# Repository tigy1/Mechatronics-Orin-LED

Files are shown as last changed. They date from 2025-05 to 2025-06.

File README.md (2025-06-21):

# Orin Robosub LED Mode Indicator

This repository contains the firmware and host-side interface for controlling a WS2812 LED strip via an STM32 microcontroller over UART. The LEDs are used to indicate the **current operational mode** of the Orin Robosub, a student-built autonomous underwater vehicle.

Modes are communicated via UART from a Python script running on the host system and translated into LED color patterns by the STM32 firmware.

---

## Purpose

LEDs provide **immediate visual feedback** on Orin’s state. This is crucial during pool testing, debugging, or when operating the sub remotely. Modes are mapped to colors, enabling surface crew to distinguish between autonomous navigation, manual override, kill switch activation, and other states.

---

## Architecture Overview

### Hardware Components

- **Microcontroller**: STM32 (e.g., STM32F103 or similar)
- **LED Strip**: WS2812B addressable RGB strip
- **Communication**: UART @ 115200 baud between host and STM32
- **Power Supply**: Regulated 5V for LED strip

### Firmware Features (`main.c`)

- Configures **TIM2 PWM with DMA** for LED signal generation
- Parses RGB input strings over UART
- Allows **real-time LED updates** from Python terminal input
- Implements **chasing animation** based on current mode color
- Brightness control via `tan()` mapping for perceived brightness tuning

### Python Host Interface (`led_script.py`)

- Validates and sends RGB values to STM32 over UART
- Command-line interface prompts for interactive control
- Cross-platform support with adjustable serial port

---

## Getting Started

### Clone the Repository

```bash
git clone https://github.com/tigy1/Mechatronics-Orin-LED.git
cd Mechatronics-Orin-LED
```

### Build and Flash Firmware

- Use **STM32CubeIDE** or compatible toolchain
- Connect your board via ST-Link or UART bootloader
- Ensure `NUMBER_OF_LEDS` is configured correctly in `main.c`
- Flash `main.c` and its dependencies (`led.c`, `led.h`) to your board

### Install Python Dependencies

No external libraries beyond `pyserial` are required:

```bash
pip install pyserial
```

---

##  Using the Control Script

Run the Python control interface:

```bash
python3 led_script.py
```

You will be prompted to enter RGB values in the format:

```
### ### ### where each chain of hashtags represents a number 001 - 255 (0s are important) as a decimal representation of RGB values.

To disable LED output via DMA, send: `001 000 000`
```

The script will validate input and send it via UART to the STM32 board.

*Adjust `port` and `baudrate` if needed inside `led_script.py`.*

---

## Code Highlights

### UART Packet Format

The STM32 expects newline-terminated ASCII RGB strings over UART:

```
"255 000 000\n"
```

Parsed using `sscanf` in `HAL_UART_RxCpltCallback()`.

### LED Color and Brightness Encoding

Color bits are stored as bitwise-shifted PWM values in structs:

```c
typedef struct {
  uint16_t r[8], g[8], b[8];
} led;
```

Brightness mapping uses `tan(angle)` to provide nonlinear control.

### DMA Timing

Each LED gets 24 bits; additional 2 LEDs are padded to ensure reset timing:

```c
NUMBER_OF_LEDS * 24 + 2 * 24
```

---

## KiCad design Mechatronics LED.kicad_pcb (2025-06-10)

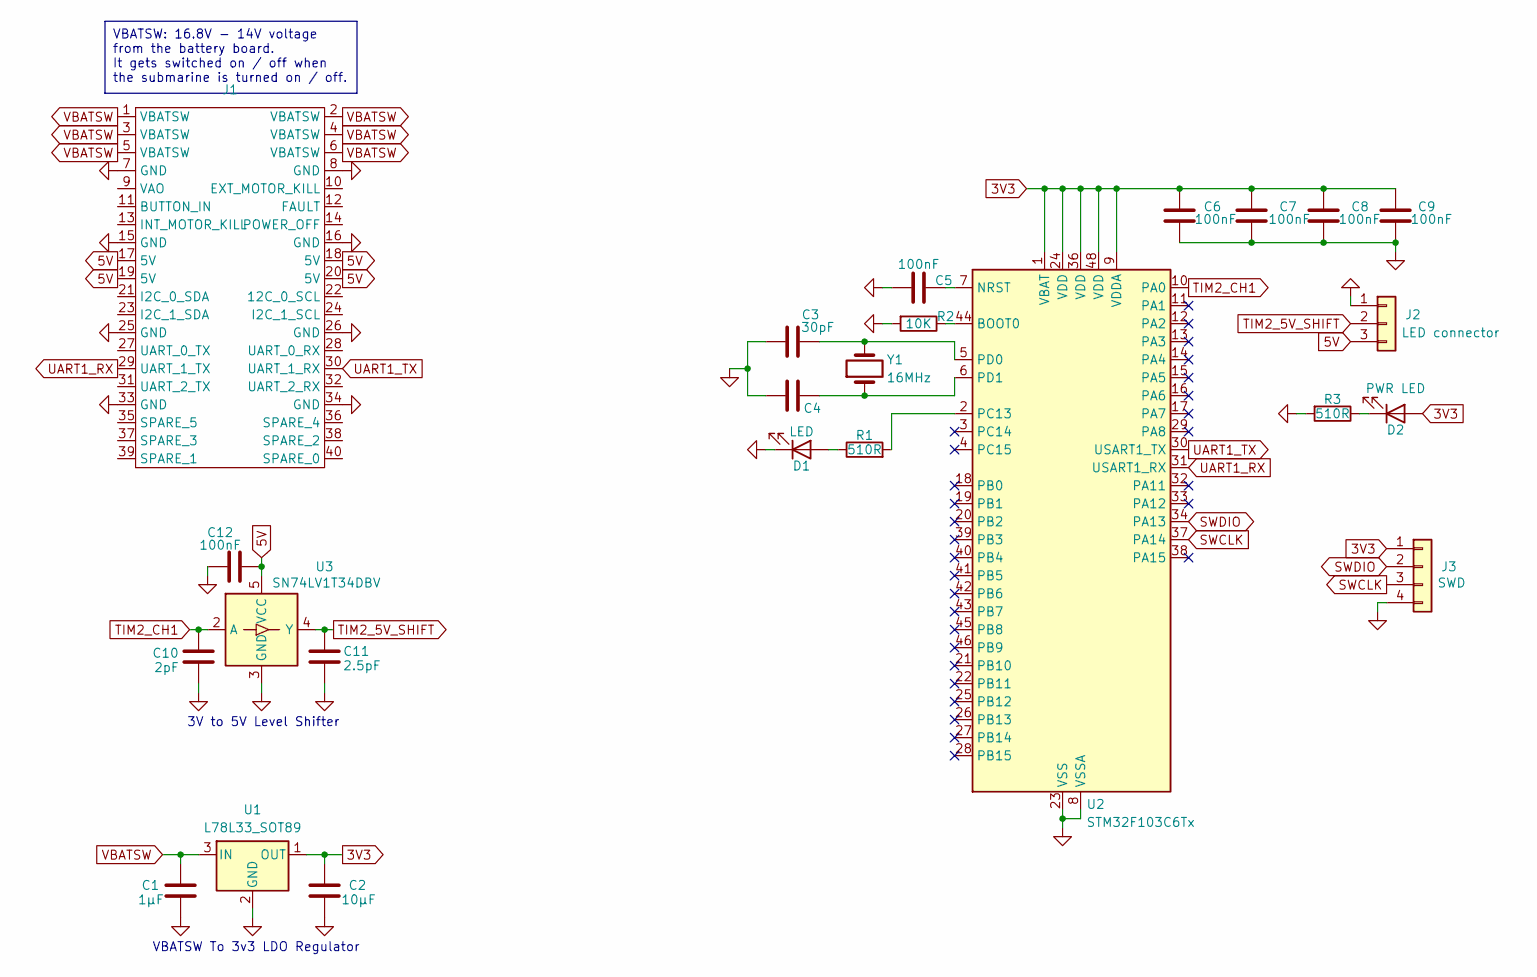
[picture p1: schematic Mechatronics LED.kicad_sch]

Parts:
C1: 1μF; C_0805_2012Metric
C2: 10μF; C_0805_2012Metric
C3, C4: 30pF; C_0805_2012Metric
C5, C6, C7, C8, C9, C12: 100nF; C_0603_1608Metric
C10: 2pF; C_0805_2012Metric
C11: 2.5pF; C_0805_2012Metric
D1: LED; LED_0805_2012Metric
D2: PWR LED; LED_0805_2012Metric
J1: PinHeader_2x20_P2.54mm_Vertical
J2: LED connector; PinHeader_1x03_P2.54mm_Vertical
J3: SWD; PinSocket_1x04_P2.54mm_Vertical
R1, R3: 510R; R_0805_2012Metric
R2: 10K; R_0805_2012Metric
U1: L78L33_SOT89; SOT-89-3
U2: STM32F103C6Tx; LQFP-48_7x7mm_P0.5mm
U3: SN74LV1T34DBV; SOT-23-5
Y1: 16MHz; Crystal_HC49-4H_Vertical

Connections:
3V3: C2.1, C6.1, C7.1, C8.1, C9.1, D2.2 (A), J3.1, U1.1 (OUT), U2.1 (VBAT), U2.9 (VDDA), U2.24 (VDD), U2.36 (VDD), U2.48 (VDD)
5V: C12.2, J1.17 (5V), J1.18 (5V), J1.19 (5V), J1.20 (5V), J2.3, U3.5 (VCC)
GND: C1.2, C2.2, C3.1, C4.1, C5.1, C6.2, C7.2, C8.2, C9.2, C10.2, C11.2, C12.1, D1.1 (K), J1.7 (GND), J1.8 (GND), J1.15 (GND), J1.16 (GND), J1.25 (GND), J1.26 (GND), J1.33 (GND), J1.34 (GND), J2.1, J3.4, R2.2, R3.2, U1.2 (GND), U2.8 (VSSA), U2.23 (VSS), U2.35 (VSS), U2.47 (VSS), U3.3 (GND)
unnamed: D1.2 (A), R1.1
unnamed: D2.1 (K), R3.1
unnamed: R2.1, U2.44 (BOOT0)
unnamed: C5.2, U2.7 (NRST)
unnamed: R1.2, U2.2 (PC13)
unnamed: C3.2, U2.5 (PD0), Y1.2
unnamed: C4.2, U2.6 (PD1), Y1.1
SWCLK: J3.3, U2.37 (PA14)
SWDIO: J3.2, U2.34 (PA13)
TIM2_5V_SHIFT: C11.1, J2.2, U3.4 (Y)
TIM2_CH1: C10.1, U2.10 (PA0), U3.2 (A)
UART1_RX: J1.29 (UART_1_TX), U2.31 (USART1_RX)
UART1_TX: J1.30 (UART_1_RX), U2.30 (USART1_TX)
VBATSW: C1.1, J1.1 (VBATSW), J1.2 (VBATSW), J1.3 (VBATSW), J1.4 (VBATSW), J1.5 (VBATSW), J1.6 (VBATSW), U1.3 (IN)

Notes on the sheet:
VBATSW: 16.8V - 14V voltage from the battery board. It gets switched on / off when the submarine is turned on / off.
3V to 5V Level Shifter
VBATSW To 3v3 LDO Regulator

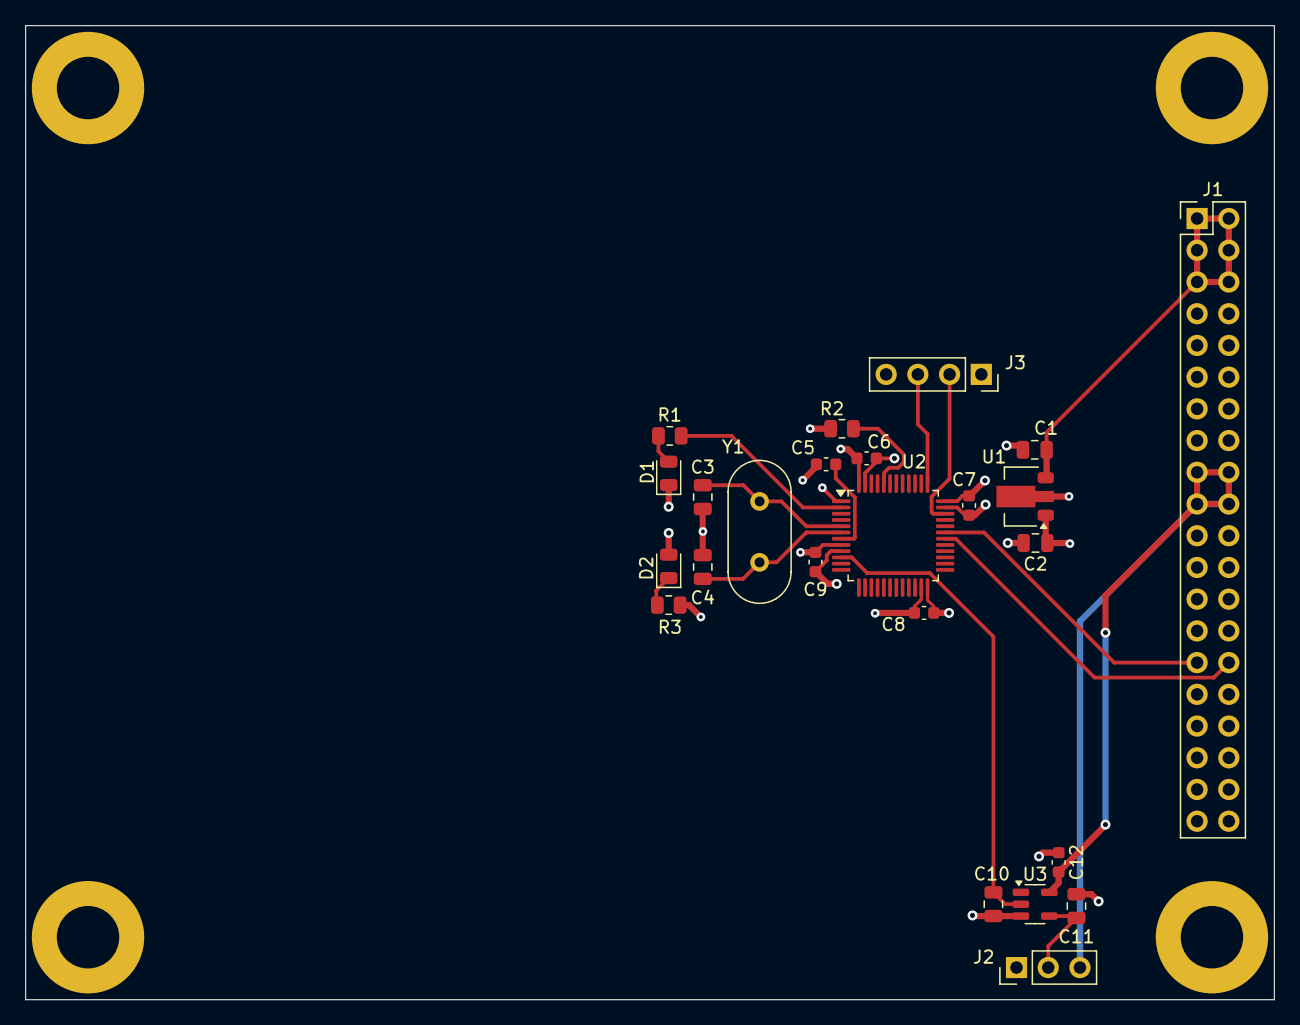
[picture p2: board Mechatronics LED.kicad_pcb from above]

Board: 4 copper layers, 100.0 x 78.0 mm, 24 parts (0 on the bottom side), 17 nets.

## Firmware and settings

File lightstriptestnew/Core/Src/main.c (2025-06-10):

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
/* Includes ------------------------------------------------------------------*/
#include "main.h"

/* USER CODE BEGIN Includes */
#include <stdio.h>
#include "string.h"
#include "led.h"
/* USER CODE END Includes */

/* USER CODE BEGIN PD */
#define NUMBER_OF_LEDS 7 //configure to # of leds
#define BRIGHTNESS 20 //configure value from 0-44, 0 = dimmest, 44 = brightest
/* USER CODE END PD */

TIM_HandleTypeDef htim2;
DMA_HandleTypeDef hdma_tim2_ch1;

UART_HandleTypeDef huart1;

/* USER CODE BEGIN PV */
led leds[NUMBER_OF_LEDS + 2]; //dma data send buffer
uint8_t RxColor[13]; //uart receive buffer
rgb_color realRGB; //LED lights as RGB values
/* USER CODE END PV */

void SystemClock_Config(void);
static void MX_GPIO_Init(void);
static void MX_DMA_Init(void);
static void MX_TIM2_Init(void);
static void MX_USART1_UART_Init(void);
/* USER CODE BEGIN 0 */

void HAL_UART_RxCpltCallback(UART_HandleTypeDef* huart){
	sscanf(RxColor, "%u %u %u\n", &realRGB.r, &realRGB.g, &realRGB.b);
	all_specific_led(leds, NUMBER_OF_LEDS, realRGB, 20);
	HAL_UART_Receive_IT(&huart1, RxColor, 12);
}

void initialize(){
	realRGB.r = 0;
	realRGB.g = 0;
	realRGB.b = 0;
	all_specific_led(leds, NUMBER_OF_LEDS, realRGB, BRIGHTNESS);
	HAL_UART_Receive_IT(&huart1, RxColor, 12); //edit for receiving preset colors?
	HAL_TIM_PWM_Start_DMA(&htim2, TIM_CHANNEL_1, (uint32_t*)leds, NUMBER_OF_LEDS * 24 + 2*24); //initializes continuous DMA
}
/* USER CODE END 0 */

/**
  * @brief  The application entry point.
  * @retval int
  */
int main(void)
{
  /* MCU Configuration--------------------------------------------------------*/

  /* Reset of all peripherals, Initializes the Flash interface and the Systick. */
  HAL_Init();

  /* Configure the system clock */
  SystemClock_Config();

  /* Initialize all configured peripherals */
  MX_GPIO_Init();
  MX_DMA_Init();
  MX_TIM2_Init();
  MX_USART1_UART_Init();
  /* USER CODE BEGIN 2 */
  initialize();
  /* USER CODE END 2 */

  /* Infinite loop */
  /* USER CODE BEGIN WHILE */
  while (1)
  {
	  //for turning off LEDS w/ uart, will stop DMA & stop accepting data just in case lol
	  if(realRGB.r == 1 && realRGB.g == 0 && realRGB.b == 0){
		  HAL_TIM_PWM_Stop_DMA(&htim2, TIM_CHANNEL_1);
	  }
//	  chasing pattern w/ 3 separate colors incrementing
	  chase_pattern_LED(leds, NUMBER_OF_LEDS, realRGB, BRIGHTNESS);
  }
    /* USER CODE END WHILE */

}

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


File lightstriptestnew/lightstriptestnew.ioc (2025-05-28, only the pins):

Mcu.UserName=STM32F103C6Tx
PA0-WKUP.Signal=S_TIM2_CH1_ETR
PA10.Signal=USART1_RX
PA13.Signal=SYS_JTMS-SWDIO
PA14.Signal=SYS_JTCK-SWCLK
PA9.Signal=USART1_TX
PC13-TAMPER-RTC.Signal=GPIO_Output
PD0-OSC_IN.Signal=RCC_OSC_IN
PD1-OSC_OUT.Signal=RCC_OSC_OUT

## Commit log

2025-05-28 Added all code for PWM LED control capabilities w/ UART
    - Inteded to run w/ UART python script to send UART data from terminal
    - Includes header & source files that store information about storing
    LED data & LED manipulation functions
    - Still incomplete, need to edit main file to clean out junk code, add
    preset LED values, and more functions to organize code
    [lightstriptestnew Debug.cfg]
2025-05-28 Added all KiCad files for PCBLED control board
    [Mechatronics LED-B_Cu.gbl, Mechatronics LED-B_Mask.gbs, Mechatronics LED-B_Paste.gbp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]
2025-06-10 Working draft of code that works w/ sending UART & PWM data
    [lightstriptestnew.cfg]
2025-06-10 Cleaned up & finalized code for LED strip setup for CaraCara sub
2025-06-10 Added LED python script for sending UART data

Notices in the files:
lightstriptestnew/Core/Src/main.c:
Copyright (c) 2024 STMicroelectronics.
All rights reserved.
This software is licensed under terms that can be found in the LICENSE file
